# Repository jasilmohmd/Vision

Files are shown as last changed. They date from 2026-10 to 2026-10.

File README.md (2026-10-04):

ï»¿# Hands-free photography rig

Follow SOFTWARE_PLAN.md for the interface contract and phase requirements.
Read [context/README.md](context/README.md), [context/HANDOFF.md](context/HANDOFF.md)
and STATUS.md before resuming work. Update context before every commit, as
required by AGENTS.md. Future-phase files are labeled placeholders.

## Phase 0 setup (PowerShell)

```powershell
python -m venv .venv
.\.venv\Scripts\python.exe -m pip install pyyaml pytest
.\.venv\Scripts\python.exe -m app.main --help
.\.venv\Scripts\python.exe -m app.main --config config.yaml --check-config
.\.venv\Scripts\python.exe -m pytest
```

Only PyYAML and pytest are needed for Phase 0. The requirements files list
later laptop and Uno Q dependencies. Ultralytics is laptop-only for export;
never install it or PyTorch on the Uno Q.

Use --check-config to validate configuration without starting devices. Phase 3
adds --mock, --mic laptop|udp (default udp), --preview and --seconds.
Relative photos_dir values resolve beside the selected YAML file. IP defaults
are examples awaiting confirmation at Gate 0. Ports follow the source contract.

## Phase 1 vision (PowerShell)

The laptop runtime uses **opencv-contrib-python** for CSRT/KCF, replacing the
base OpenCV package from the original scaffold. Uno Q requirements use its
headless contrib equivalent. Install one cv2 distribution per environment:
[OpenCV package guidance](https://pypi.org/project/opencv-contrib-python/).

```powershell
.\.venv\Scripts\python.exe -m pip install "opencv-contrib-python>=4.10,<5" onnxruntime numpy
.\.venv\Scripts\python.exe -m tools.download_models
```

YOLOv8n exports at 320 pixels with a static FP32 batch-one input and raw outputs
(no embedded NMS). Export dependencies live in a separate laptop environment
because Ultralytics depends on base OpenCV:

```powershell
python -m venv .venv-export
.\.venv-export\Scripts\python.exe -m pip install -r requirements-export.txt
.\.venv-export\Scripts\python.exe -m tools.export_onnx
```

The downloader fetches official YuNet and Vosk small English models. The shell
wrapper is `bash tools/download_models.sh` (set PYTHON to your venv Python on
Linux). Models and benchmark reports live in ignored models/; downloads need
internet, but runtime inference runs locally using ONNX Runtime and OpenCV.

```powershell
.\.venv\Scripts\python.exe -m tools.demo_vision --target person
.\.venv\Scripts\python.exe -m tools.bench_vision --frames 100 --output models/benchmark-webcam.json
.\.venv\Scripts\python.exe -m pytest
```

Move across the webcam view and confirm the box follows smoothly. The preview
shows the target and normalised dx/dy; the console prints the box and offset
per frame. Press Q or Escape to exit. Positive dx is right, positive dy is down,
and (0, 0) means centred; absent targets return (None, None).

Use --target face|dog|cat, --tracker KCF, --source 1 for another webcam, or
--source path/to/video.mp4. A video file is useful for repeatable benchmarks.
Demo --headless --frames 100 prints offsets without opening a window.
Benchmarks exclude acquisition time, preload the same 320x240 frames for both
runs, and report detected/tracked frame counts; a run without a target does not
measure normal tracking performance. CSRT is preferred with KCF fallback;
detection refreshes every configured N frames and immediately after a failure.
New boxes associate with the closest previous box centre; confidence chooses
the initial target. A missing detection clears the active target.

Ultralytics YOLOv8 weights are AGPL-3.0, as noted in SOFTWARE_PLAN.md.
Model/export references: [Ultralytics ONNX export](https://docs.ultralytics.com/modes/export),
[OpenCV YuNet](https://github.com/opencv/opencv_zoo/tree/main/models/face_detection_yunet),
[Vosk models](https://alphacephei.com/vosk/models),
and [FaceDetectorYN API](https://docs.opencv.org/4.x/df/d20/classcv_1_1FaceDetectorYN.html).

## Phase 2 voice (PowerShell)

```powershell
.\.venv\Scripts\python.exe -m pip install vosk sounddevice
.\.venv\Scripts\python.exe -m tools.demo_voice --list-devices
.\.venv\Scripts\python.exe -m tools.demo_voice --list-commands
.\.venv\Scripts\python.exe -m tools.demo_voice --mic laptop --device 3
```

Device 3 was this laptop's AMD microphone array during development; the default
input was a virtual Elgato line. Check device IDs on each machine and choose the
actual microphone; this does not change the system default. Ctrl+C stops the demo.
Use --seconds 30 for a finite run. Events are printed as JSON: heard, command
(with a typed action/target/direction/small-step flag), or low_confidence.
The standalone Phase 2 demo prints events only. The Phase 3 app applies commands.

Vosk uses all 19 exact "camera <command>" phrases plus [unk]. A final command
requires the leading wake word and confidence at or above config.vosk_conf_threshold
for every word, including "camera". Empty/[unk] results are ignored; other rejected
non-empty results emit low_confidence. Partial "camera" emits heard once per utterance.

Keep quiet for the two-second startup microphone sample, then wait for Ready.
Speech is separated after about 0.7 seconds of quiet, retaining a short lead-in
so the wake word is not cut off. Say one complete command at a time and pause
for its response. Commands still require the full wake phrase and word
confidence threshold. Closing the app discards unfinished speech rather than
turning it into a command. Loud startup samples are bounded; actual headset,
quiet speech and background-chatter reliability still need live checks.

Run the guided acceptance check from 0.5-1 m away:

```powershell
.\.venv\Scripts\python.exe -m tools.demo_voice --device 3 --checklist --report logs/phase2-voice-check.json
```

Say each prompted phrase, pause for its command event and repeat if rejected.
After all 19 commands, talk normally for the prompted 20-second background test,
without saying command phrases. It should produce no command events. The summary
records coverage and false commands, not raw audio or chatter transcripts. A
passing summary still needs confirmation that the distance and chatter conditions
were actually exercised. No recording is saved. Ctrl+C produces an incomplete
summary if you stop early. --background-seconds can adjust the test duration.

UDP mode is also runnable without real hardware:

```powershell
.\.venv\Scripts\python.exe -m tools.demo_voice --mic udp --seconds 30
```

It binds config.audio_port (5005 by default) on 0.0.0.0. Each datagram must contain
512 mono s16le samples (1024 bytes) at 16 kHz. A bounded arrival-order queue buffers
jitter, drops old backlog and inserts 32 ms silence chunks for missing playout slots.
The raw contract has no sequence numbers/timestamps, so it cannot reconstruct packet
reordering or exact losses. Before any valid packet, read_chunk returns empty on
short timeouts. Closing the source releases its receiver thread/socket.

API references: [Vosk microphone example](https://github.com/alphacep/vosk-api/blob/master/python/example/test_microphone.py),
[Vosk recognizer API](https://github.com/alphacep/vosk-api/blob/master/python/vosk/__init__.py),
[sounddevice raw streams](https://python-sounddevice.readthedocs.io/en/latest/api/raw-streams.html).

For no-response diagnosis, demo_voice --levels prints input RMS/peak once per
second and the selected input name. Verify --list-devices after connecting a
headset; IDs can change. Nonzero changing levels show capture activity, not
successful recognition. Headset tests are diagnostic and do not by themselves
replace the planned laptop-microphone acceptance at 0.5-1 m.

## Phase 3 mock rig (three PowerShell terminals)

Install laptop dependencies with `.\.venv\Scripts\python.exe -m pip install -r requirements-laptop.txt`.
Models must already exist locally (see Phase 1/2 setup above). From the repository
root, run one command in each terminal. Start the camera mock first and wait
for "Mock camera ready" before starting the app (webcam startup can take a while):

```powershell
.\.venv\Scripts\python.exe -m tools.mock_camera
.\.venv\Scripts\python.exe -m tools.mock_voice_unit --device 4
.\.venv\Scripts\python.exe -m app.main --mock --preview
```

Device 4 is the verified boAt headset on this laptop; check `tools.demo_voice
--list-devices` before using another computer. The voice mock sends live 16 kHz
mono s16le audio in 1024-byte UDP packets, and prints light states/colours. The
app uses UDP audio by default; `--mic laptop --device N` bypasses the voice mock
for diagnosis. It does not change the system microphone setting.

Wait for "Ready", say **camera track person**, then move left/right. The camera
mock shifts its 320x240 crop inside the full webcam image; the preview shows the
box, offsets and pan/tilt. A narrow crop may require standing farther back or
moving into its initial centre. Say **camera shoot**, check the `saved` white
flash in the voice console, and open http://localhost:8080. Tap the newest photo
to open its full resolution. The gallery refreshes when a new photo is saved.
Press Q in the preview, then Ctrl+C in both mock terminals.

Manual direction/small-step/centre commands work while idle or tracking. Stop
tracking returns to idle; sleep ignores commands until camera wake. Burst saves
three photos about 400 ms apart after centering; timer flashes blue three times
then shoots. Missing subjects produce nosubject after two seconds. Movement is
limited to ten requests per second and configured angle limits. Captures wait
for centering or the configured timeout, save before ACK, and retain camera
photos if saving fails. A failed ACK is retried before another capture.

`photos/` (including index metadata), model files and diagnostic logs are Git
ignored. Runtime needs write access to photos_dir. Only one app instance may
write the same photo directory. Optional `speaker_enabled: true` uses eSpeak NG
or eSpeak when installed; disabled/missing synthesis is a no-op.

For headless diagnostics, camera `--synthetic` or `--image path.jpg` avoids the
webcam; voice `--silence` avoids microphone access; all three support --seconds.
The mock HTTP/UDP ports match the shared contract exactly. `--mock` only changes
camera/light destination addresses to localhost; real board/network integration
waits for the plan's hardware gates. Firmware is owned by separate Session B.

## Phase 5 Uno Q deployment

See [deploy/README.md](deploy/README.md) for source/model transfer, the Linux
installer, laptop LAN mocks, phone-gallery acceptance and Uno Q benchmark.
S3/C3 IPs are deferred; this phase uses laptop mocks. Do not run --mock on Uno Q
when its mock servers are on the laptop; use the separate config.phase5.yaml.

## Live tracking view on Uno Q

After confirming hardware gates and updating board addresses in config.yaml,
run from the deployed project directory:

```bash
.venv/bin/python -m app.main --config config.yaml --mic udp --seconds 0
```

Open `http://<UNOQ_IP>:8080/live` on the laptop or phone on the same network.
The page shows the existing camera feed with its tracking box, mode, pan/tilt
and offsets; it does not open another S3 stream. Say **camera track person**
to follow a person and **camera stop tracking**, then pause, to return to IDLE.
Use the Camera roll link for saved photos. Ctrl+C in the app terminal stops
the run; `--seconds 0` has no time limit.

Current hardware blockers and the temporary serial-reader workaround are
recorded in [power diagnosis](context/HARDWARE_POWER_ISSUE.md) and
[C3 audio diagnosis](context/FIRMWARE_AUDIO_ISSUE.md). Publication does not
mean these hardware acceptance checks have passed.

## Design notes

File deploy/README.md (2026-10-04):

# Phase 5: Uno Q against laptop mocks

## Prepared robustness service (2026-10-04)

The requested robustness implementation includes `photo-rig.service`.
It runs the UDP microphone app from `/home/arduino/Vision` as `arduino`, waits
for network startup and restarts after exit. It is prepared, not installed or
enabled: hardware acceptance and the S3 power correction remain pending.
Use the real-board `config.yaml`, verified current addresses, models and venv.
Do not use `config.phase5.yaml` for the service.

When hardware acceptance permits activation, on the Uno Q:

```bash
cd /home/arduino/Vision
.venv/bin/python -m app.main --config config.yaml --check-config
systemd-analyze verify deploy/photo-rig.service
sudo install -m 644 deploy/photo-rig.service /etc/systemd/system/photo-rig.service
sudo systemctl daemon-reload
sudo systemctl enable --now photo-rig.service
systemctl status photo-rig.service
journalctl -u photo-rig.service -n 50 --no-pager
```

Stop any manually launched app first so its UDP/gallery ports are released.
If using another directory or user, update the unit paths before installation.
To stop auto-start: `sudo systemctl disable --now photo-rig.service`.
The app writes JSON lines to `logs/vision.jsonl`, rotates at UTC midnight and
keeps seven rotated files. `--log-dir` overrides the destination. Camera outages
mask the normal light state with `reconnect`; recovery synchronizes servo
positions and recreates the tracker for the retained target. Missing valid C3
packets for over five seconds warns once per outage without stopping the app.
Generated silence does not count as incoming C3 audio. Sleep keeps the light off.
See `tools/prototype_acceptance.md` for the later combined hardware check.

This phase deploys the Linux software and models and measures Uno Q performance.
No S3/C3 addresses, firmware flashing or systemd service are required. Physical
integration begins only at later gates. Service/autostart work belongs to Phase8.

## Known network and login

User supplied Uno Q LAN IP10.153.76.45 and confirmed SSH/hotspot readiness.
Laptop Wi-Fi IP10.153.76.189 was observed locally when preparing this phase.
Recheck both after changing networks. User confirmed SSH username arduino; no password is stored in scripts or context. The laptop and Uno Q must be mutually reachable,
not merely have access to the same hotspot; disable hotspot client isolation if
it prevents this. Keep host-key verification enabled.

## Copy and install from PowerShell

From the repository root:

```powershell
.\deploy\copy_to_unoq.ps1 -User arduino -UnoqIp 10.153.76.45 -LaptopIp 10.153.76.189
```

This packages runtime source and the three required models, copies two archives
via scp to ~/Vision, then runs the installer over SSH. SSH/sudo prompts are entered
in your own terminal, never in chat. Existing photos and normal config.yaml are
preserved. Generated config.phase5.yaml intentionally points both mock endpoints
at the laptop IP; do not use it as a real-board config. Archives/source/model
checksums and generated local config are in ignored logs/. Firmware, photos,
export .pt weights, virtual environments and secrets are excluded from transfer.

`-SkipInstall` only copies/extracts. On the Uno Q, install/check separately:

```bash
cd ~/Vision
bash deploy/install_unoq.sh
# Already prepared OS packages: add --skip-apt
# Recheck existing runtime without installs:
bash deploy/install_unoq.sh --check-only
```

Installer creates project .venv, installs headless contrib/ORT/Vosk/Flask etc.,
verifies models and writable storage, and writes logs/phase5-preflight.json.
It installs missing Debian python3/venv/pip/libgomp/libatomic packages if needed.
No export dependencies on Uno Q. Missing binary wheels stop installation rather
than build OpenCV/ORT from source. Record architecture/Python and the exact error
if this happens. Setup downloads packages; runtime model inference works offline.
Use a different -RemoteDirectory if ~/Vision is used by another deployment.

## Run laptop mocks

On the laptop, in separate terminals, select your actual microphone device ID:

```powershell
.\.venv\Scripts\python.exe -m tools.mock_camera --bind 10.153.76.189
.\.venv\Scripts\python.exe -m tools.mock_voice_unit --host 10.153.76.45 --bind 10.153.76.189 --device MIC_ID
```

Device IDs can change after reconnecting; choose the current input with demo_voice --list-devices.
Wait for camera ready before running the Uno Q app. Allow this project Python
through Windows Firewall for the shared network if prompted. Required traffic:
Uno Q -> laptop TCP80/81 and UDP5006; laptop -> Uno Q UDP5005; phone -> Uno Q TCP8080.
The default camera mock binds localhost, so --bind is essential for LAN testing.
Stop the laptop app; the app now runs only on Uno Q and laptop only runs mocks.

## Run app on Uno Q and accept from phone

```bash
cd ~/Vision
.venv/bin/python -m app.main --config config.phase5.yaml --mic udp
```

Do NOT add --mock here: localhost would mean the Uno Q, not the laptop. Do NOT
add --preview to the headless runtime. Say camera track person and move inside
the laptop webcam view; view http://10.153.76.189:81/stream from a laptop browser
to observe the crop. Say camera shoot and confirm saved in the mock light console.
From a phone on the same network, open http://10.153.76.45:8080 and confirm the
newest photo opens at full resolution. Stop the app with Ctrl+C before benchmarking.
No physical NeoPixel is needed for the mock's printed light message.

## Benchmark on Uno Q

With laptop camera mock still running and a person visible in its crop:

```bash
cd ~/Vision
.venv/bin/python -m tools.bench_vision --config config.phase5.yaml --source http://10.153.76.189:81/stream --target person --frames 100 --output logs/phase5-benchmark.json
```

Record detected/tracked frames and detector-only/detector+tracker FPS, architecture
and Python/library versions from preflight. This benchmark excludes acquisition
and preloads frames; it is CPU processing FPS, not end-to-end network throughput.
Do not treat a no-subject run as a representative tracking benchmark.
If tracking is slow, benchmark --tracker KCF and start app --tracker KCF, or raise
detect_every_n_frames in config.phase5.yaml and measure again. Changing static
ONNX input size requires a fresh laptop export; never install export tools on Uno Q.

Return preflight, benchmark numbers, phone-gallery and voice/tracking/photo results.
Update STATUS/context with actual results before committing. Phase5 remains
incomplete until these checks pass. Stop at SOFTWARE_PLAN GateA afterward.

References: [Arduino Debian/SSH guide](https://docs.arduino.cc/tutorials/uno-q/debian-guide/),
[ONNX Runtime Python platforms](https://onnxruntime.ai/docs/get-started/with-python.html).

## Current prepared USB test deployment (2026-10-04)
The current DHCP observations are Uno Q10.153.76.45 and laptop10.153.76.189.
Recheck these before testing; the earlier addresses above are historical examples.
User installed ADB separately and confirmed USB device serial662499217. The
latest source was copied over USB into /home/arduino/Vision-phase5-20261004,
with its own models/config/photos and the existing ~/Vision runtime venv.
Original ~/Vision is retained. Runtime/model preflight passed; live acceptance
and benchmark are deferred until the user is ready. App Lab is not required
for this direct Linux Python workflow.

When ready, start the camera/voice mocks on the laptop using the current IPs
and confirmed headset device. From the user's Platform Tools directory:

```powershell
.\adb.exe -s 662499217 shell -t "cd /home/arduino/Vision-phase5-20261004 && .venv/bin/python -m app.main --config config.phase5.yaml --mic udp"
```

Keep this terminal open. Once a photo is saved, the phone gallery is
http://10.153.76.45:8080 on the same network. After stopping the app, keep the
laptop camera mock running and benchmark:

```powershell
.\adb.exe -s 662499217 shell -t "cd /home/arduino/Vision-phase5-20261004 && .venv/bin/python -m tools.bench_vision --config config.phase5.yaml --source http://10.153.76.189:81/stream --target person --frames 100 --output logs/phase5-benchmark.json"
```

Do not report Phase5 passed from preflight alone. SSH also listens on port22,
but the new IP's host key has not yet been enrolled in the laptop's SSH client;
use the trusted USB connection to verify it rather than disabling verification.

## Stream troubleshooting and quote-safe runner

After copying the latest source, use the Linux runner to avoid Windows SSH command
quoting problems. It checks for existing app processes and stops on guard errors:

```bash
bash deploy/run_phase5.sh network   # 60s read-only camera status/stream check
bash deploy/run_phase5.sh live      # ten-minute app; stop old app first
bash deploy/run_phase5.sh benchmark # 100 person frames; stop app first
```

Network results go to logs/phase5-network-unoq.json. The check counts received
JPEGs and chunk gaps; it does not capture/save photos, ACK, move, or benchmark
inference. A steady local stream with remote timeouts needs network diagnosis;
keep firewall enabled and examine the shared hotspot connection. Do not count
runtime setup or HTTP gallery access as full spoken/phone acceptance.

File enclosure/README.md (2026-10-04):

# Vision enclosure models

Self-contained, editable OpenSCAD code for all seven designs in the supplied
`ENCLOSURE_PROMPTS.md`. The reference is at `../../ENCLOSURE_PROMPTS.md` relative
to this folder. No libraries are required. All dimensions are millimetres.

## Use

1. Open `vision_enclosures.scad` in OpenSCAD, or paste its entire contents into
   the playground, replacing the example code.
2. Change `part = "layout";` to a selection from the table below.
3. Replace the typical component sizes and the explicitly marked position
   placeholders near the top of the file with measurements.
4. Preview, render, then export one selected part as STL. In desktop OpenSCAD,
   use F5 for preview and F6 for render, then File > Export > Export as STL.
5. Use `camera_assembly` and `preview_tilt` to inspect the camera arrangement.
   This view omits purchased servos, horns, screws, boards and cables. It is
   not an STL to print and does not constitute a collision or load test.

| Selection | Result |
| --- | --- |
| `layout` | Eight separate pieces laid out for viewing, using horizontal C1 |
| `camera_assembly` | Assembled camera enclosure preview |
| `C1` | Pan pod with horizontal-axis tube clamp and tripod nut pocket |
| `C1_vertical` | Alternative with vertical-axis tube clamp behind the pod |
| `C2` | Pan yoke, tilt-servo window and pivot spacer |
| `C3` | Camera front shell, PCB ledges and hinge mounting plates |
| `C4` | Camera rear bay, perfboard rails, vents and strain-relief bridge |
| `P5` | Voice enclosure with breadboard locator, spare bay and strap ears |
| `P6` | Matching voice lid |
| `P7_front` | Mic pod half containing the angled NeoPixel diffuser |
| `P7_back` | Other mic pod half |

Example:

```scad
part = "C3";
```

The nine default STL exports and two previews are in `validation/`. They are
prototype exports using typical sizes, not measurement-approved production files.
Regenerate them after changing parameters. Never export the layout as one part.

## Deliberate corrections and prototype limitations

The reference contains conflicting dimensions and printing constraints. These
models resolve some geometrically and make the remaining limits explicit:

- Camera outer body: **40.8 x 76.8 x 39.6 mm**. Its larger footprint allows for
  the 30 mm perfboard and corner fasteners, beyond the 28 mm camera PCB.
- Rear depth: **25.6 mm**, derived from 10 mm header separation + 1.6 mm perfboard
  + 12 mm component space + 2 mm rear wall. The original 20 mm cannot hold that
  stack. Actual pin lengths and capacitor clearance still need checking.
- Hinge plates extend rearward from C3 to put the tilt axis at assembled
  mid-depth. The original 10 mm circular boss cannot contain a 20 mm horn.
  The enlarged horn pocket takes a conservative 20 mm hub-to-tip length.
- Yoke inner gap: **69.8 mm**, allowing 11.5 mm per side beyond the case bosses.
  This includes the provisional 8.5 mm servo projection and 2 mm horn thickness.
  A matching spacer on the pivot arm fills its extra distance. The base is
  **76.4 x 44.8 mm**, expanded to contain both the arms and the horn pocket.
  Measure the servo tab-to-output-face distance before selecting final spacing.
- The tilt axis remains 48 mm above the plate top. Its height also increases
  automatically if the case diagonal grows. This gives a conservative body-to-
  plate envelope, but does not check ribs, cables, screws or the actual servo.
- C1's bearing ring is approximately **37.77 mm inside diameter, 9 mm tall**:
  its diameter clears the off-centre servo body and its height follows the
  assumed servo/horn stack. A 30 mm ring only 1 mm above the mounting tabs would
  collide with that body or fail to reach the yoke. The bearing surface is not
  a load-rated bearing. The pod is intentionally thick around the mount.
- The vertical clamp is offset behind the pod to keep its tube bore open.
  C1's origin is the pan shaft axis at bed height, rather than the centre of
  its asymmetric tripod flange footprint. The horizontal clamp has a 90-degree
  mouth (270-degree wrap). Interference is diametral and requires a fit coupon.
- The camera USB cut-outs continue into the rear rim where needed. The cable
  notch opens to that rim for assembly and avoids tiny detached tabs.
- C3's optional outward lens hood defaults to **off** (`camera_hood = 0`) so
  its front lies flat on the bed. Set it to 1.5 for a hood and revise supports
  or print orientation. Labels are 0.6 mm engravings, rather than raised text
  underneath the print. They are optional.
- Voice interior: **96.8 x 49.6 x 30 mm**. Space is reserved for the breadboard
  and optional battery/charger, but the spare bay has no battery-specific clips
  or charger standoffs. Secure and insulate those components separately. USB
  positions are placeholders. Strap slots are external ears to isolate straps
  from the electronics.
- P7 uses a **30 mm nominal diameter x 52 mm nominal length** capsule to make
  room for the mic, header space, LED and 12 mm arm socket. Its ports remove
  the extreme tips; the angled diffuser also projects above the capsule.
  Both halves print with their split planes on the bed. Front screw seats use
  counterbores, not conical countersinks. The diffuser is a 1 mm solid window
  angled 30 degrees; use translucent/natural material. Transmission is untested.
- `mic_sound_x` and `mic_sound_z` must match the actual acoustic port, and the
  module's acoustic side must face the tip. The two clamped halves capture it;
  the 0.8 mm retaining rim is a local exception to the 1.2 mm minimum feature.
- Curved clamp bores, horizontal pivot/horn pockets, rear guides, the offset
  vertical clamp platform and pod roofs may need supports or reorientation.
  **Support-free printing, uniform 3 mm fillets, all overhangs below 45 degrees,
  and bridges below 20 mm have not been achieved or certified.** Rounded planar
  footprints use chamfers; curved clamps/pods do not have universal bottom chamfers.
- Camera rear fasteners pass through the deep bay, so the reference's M2 x 6 mm
  screws are too short. Allow roughly 30-32 mm screw length (verify head seating
  and engagement). The enlarged pivot spacer also needs a longer pivot screw.
  Select actual screw and clamp-bolt lengths after the fit test.

## Validation performed on 2026-10-04

Rendered with the official portable OpenSCAD 2021.01 Windows build from the
[OpenSCAD download page](https://openscad.org/downloads.html), without installing
it system-wide. Each of the nine part exports reported `Simple: yes`.

`python enclosure/check_meshes.py` checks the exported ASCII STLs using the
Python standard library. All nine default exports passed: one connected mesh,
every edge shared by two faces, consistent edge winding, no zero-area triangles
and positive signed volume. See `validation/mesh_report.json` and individual
render logs. Layout and camera assembly previews were visually inspected.

These checks establish default-export geometry only. They do not establish
component fit, arbitrary parameter combinations, slicer support requirements,
clamp holding force, servo torque, thermal performance, acoustics, or full
pan/tilt motion. No hardware or software-phase acceptance is inferred.

Before printing the full set, measure the components, make a clamp/horn/lip fit
coupon, inspect each sliced layer, and assemble and sweep the mechanism on a
bench. Confirm sound-port alignment and secure mounting before use near a person.

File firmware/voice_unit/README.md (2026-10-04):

# C3 voice unit (F3)

User-confirmed C3 SuperMini wiring: INMP441 SCK GPIO4, WS GPIO5, SD GPIO6,
VDD3V3, common GND, L/R grounded. External NeoPixel DIN GPIO7, GRB, brightness40.
F1 microphone conversion uses SHIFT14. Optional IR is omitted in this prototype.

Copy ../secrets.example.h to ignored secrets.h and enter Wi-Fi credentials
locally. UNOQ_IP is the audio receiver's confirmed address, not the C3 address.
Use the laptop destination for the standalone bench checker; use the Uno Q
destination for integration. Initial addressing may use WIFI_USE_DHCP=1 to read
the C3 address from Serial. Static production addressing requires confirmed
C3_IP/GATEWAY/SUBNET; never invent those values. No credentials belong in Git.

The audio task reads mono left-channel I2S at16kHz/32bits, clips after SHIFT,
and sends exactly512 signed16bit little-endian samples per UDP5005 datagram.
It drains audio while offline and does not replay a disconnected backlog.
The main loop independently receives UDP5006 light states, using timers rather
than blocking flash/blink delays. heard/saved last300ms; error gives two150ms
red flashes with150ms gaps, then the previous steady state. Wi-Fi down overrides
the display with blinking purple. Unknown/malformed light messages are ignored.
Automatic reconnect remains enabled; manual retries wait45s for an in-progress WPA3 handshake. Serial prints disconnect reason, IP, reset reason, packet send counts,
send errors and signal level. Successful UDP send is not receiver acknowledgement.

From repository root, with the portable toolchain and installed libraries:

```powershell
& ./firmware/.toolchain/arduino-cli.exe compile --fqbn 'esp32:esp32:esp32c3:CDCOnBoot=cdc' --libraries ./firmware/.toolchain/user/libraries --build-path ./firmware/.build/voice_unit ./firmware/voice_unit
# Upload only after explicit user authorization and verifying the C3 port.
& ./firmware/.toolchain/arduino-cli.exe upload --fqbn 'esp32:esp32:esp32c3:CDCOnBoot=cdc' --port COM18 --input-dir ./firmware/.build/voice_unit ./firmware/voice_unit
```

Read Serial115200 for the DHCP address. PortCOM18 is the observed C3 connection,
not a guaranteed permanent port. If USB upload fails, use the already-tested
BOOT/reconnect procedure and retry only after the user confirms readiness.

Run firmware/tools/check_voice_unit.py on the configured audio receiver:

```powershell
./.venv/Scripts/python.exe firmware/tools/check_voice_unit.py --ip <C3_IP>
```

Stop other UDP5005 receivers first. This intentionally records five seconds of
microphone audio locally into ignored firmware/.build/voice_checks/check.wav
and cycles all light states. Get the user's readiness before recording/colour
checks. Raw packets have no sequence header, so packet loss is only estimated
from expected rate, never exactly measured. Listen to the WAV and observe the
physical colours before claiming acceptance. Compilation/boot alone does not
establish microphone quality, colour accuracy or end-to-end voice recognition.

Earlier build2026-10-04: compiled and flashed999581 program bytes/37976 globals,
verified C3 COM18/ESP32-C3 AZrev1.1. Explicit SAE-both negotiation is enabled.
Wi-Fi authentication still expires on the tested WPA3 hotspot; no C3 DHCP IP
confirmed yet. Packet, microphone quality and physical light checks are pending.
Try the existing hotspot in2.4GHz/WPA2-Personal with its unchanged current
password before additional firmware changes; this is a diagnostic next step,
not a claim that the ESP32-C3 lacks WPA3 support. Confirm actual network details
before changing destinations or declaring acceptance.

For C3 headers, select C/C++: Select a Configuration -> ESP32-C3 SuperMini in
VS Code/Cursor, then reload the editor window. The workspace provides separate
S3 and C3 compiler/SDK paths and associates .h/.ino with C++; pragma once itself
is valid and the full C3 sketch compiled successfully. Keep headers' board
configuration matched to the current sketch. Editor paths are validated locally;
visual diagnostic clearance still requires checking the editor.

## Latest Wi-Fi troubleshooting

The default-power Wi-Fi-only sketch detected the WPA2 hotspot at-47dBm but
failed to connect. The diagnostic capped transmit power at8.5dBm (ESP-IDF34)
and confirmed DHCP10.153.76.243, gateway10.153.76.224, RSSI around-43dBm.
Production now applies the same cap after starting STA, before connecting.
It compiled999841 program bytes/37976 globals and uploaded with verified hashes.
After restoration,10.153.76.243 answered two pings and its neighbour entry matched
C3 MAC44:b1:76:17:f5:7c. Serial showed packet-send counts240/553/866; five initial
send errors did not increase in those subsequent reports. This establishes
connection and sender activity, not receipt or microphone quality.
This is an observed working setting for this board/network, not proof of an
antenna/power fault or a universal fix. Production connectivity and F3 audio/
light acceptance must be checked separately. Diagnostic source is preserved
under ../bench/wifi_diagnostic; credentials remain ignored.

## Nonblocking diagnostic logging — prepared 2026-10-04
Audio/event tasks enqueue bounded debug messages without waiting. Main loop
drains only when USB has capacity; CDC TX timeout is zero. Full queues drop logs
instead of delaying PCM delivery. Compile passed on core3.3.11:999975 program
bytes/37976 globals. This repair is NOT flashed yet; hardware testing is deferred.
After confirmed flashing, run sustained delivery with serial monitor CLOSED for
at least40seconds, measure rate/max gaps, then verify speech and light patterns.
See ../../tools/prototype_acceptance.md. IR remains omitted.

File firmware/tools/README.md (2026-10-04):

# Hardware checks

verify_toolchain.ps1 compiles the F0 probe; verify_bench.ps1 compiles all four
F1 bench sketches with optional simultaneous-servo variant. Neither uploads.
See ../TEAM_TESTING.md for manual upload commands and physical acceptance.

Phase F2: check_camera.py --ip <S3_IP> exercises status, a small servo pattern,
QVGA MJPEG, higher-resolution capture, retained-photo retry, ack and stream
recovery. Requires requests. JPEGs default to ignored ../.build/camera_checks/.
The checker also moves pan/tilt through85..95degrees during active streaming,
prints each move latency, requires acknowledgements below2s, and checks
commanded slew plus fresh video frames. These are software readbacks; the user
must still verify actual direction, smoothness and return to neutral.
Target/command readback cannot measure physical servo position; observe motion.
Do not run simultaneously with the app: the stream server serves one viewer.

check_voice_unit.py remains a Phase F3 task.

Phase F3: check_voice_unit.py --ip <C3_IP> runs on the configured audio receiver.
It records5s of UDP5005 PCM to ignored .build/voice_checks/check.wav, checks1024
byte packet sizes and observed rate/RMS/peak, then sends all8 light states.
User readiness is required before the microphone/colour checks. It cannot
measure exact packet loss because the contract PCM datagrams have no sequence
numbers; estimated rate shortfall is reported explicitly. IR remains omitted.

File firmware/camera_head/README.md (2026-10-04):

# S3 camera head (F2)

Board: user-confirmed ESP32-S3 CAM N16R8, OV3660. GPIO1 pan, GPIO2 tilt.
Camera signals match the supplied pinout and installed core ESP32S3_EYE entry;
PWDN/RESET are -1 in that entry and must be validated by camera initialization.
OPI PSRAM is required. F1 horns were aligned at 90/90; this sketch centres on
boot without an automatic sweep. There is no physical position feedback.

Copy ../secrets.example.h to secrets.h and configure Wi-Fi locally. Never commit
secrets.h. Production defaults to static addressing; user approved
WIFI_USE_DHCP=1 for the first bench check. All devices need the same 2.4 GHz
network without client isolation.

From repository root (portable toolchain used in this workspace):

```powershell
& ./firmware/.toolchain/arduino-cli.exe compile --fqbn 'esp32:esp32:esp32s3:PSRAM=opi,FlashSize=16M' --libraries ./firmware/.toolchain/user/libraries --build-path ./firmware/.build/camera_head ./firmware/camera_head
# Run upload only after Gate F2 confirmation; recheck the connected board/port.
& ./firmware/.toolchain/arduino-cli.exe upload --fqbn 'esp32:esp32:esp32s3:PSRAM=opi,FlashSize=16M' --port COM19 --input-dir ./firmware/.build/camera_head ./firmware/camera_head
& ./.venv/Scripts/python.exe firmware/tools/check_camera.py --ip <IP_FROM_SERIAL>
```

Serial115200 reports PSRAM, camera PID, IP, capture dimensions and errors.
HTTP control is port80; MJPEG is port81. Stream is QVGA320x240 JPEG quality12.
Video is capped at10fps to leave Wi-Fi airtime for control requests. Servo
targets and PWM updates have a separate mutex from camera frame acquisition;
a slow frame cannot hold the servo lock. Capture still freezes servo updates
while acquiring the photo. The checker also measures move latency and checks
commanded slew while an active stream is being consumed. Physical direction
and actual movement require observation; status angles are software commands.
Servo slew runs in a dedicated task, independently of Wi-Fi reconnect work in
the Arduino loop, with at most2degrees per20ms and no burst to catch up missed
periods. Status diagnostics move_received_ms, move_settled_ms and
move_in_progress measure command handling and completion of commanded PWM
updates, not physical servo position. Millisecond values wrap after49days.
Serial logs each accepted move with handler duration; speech recognition
latency on the laptop is outside this firmware's timing measurements.
Capture attempts QXGA2048x1536, then lower sizes if capture/allocation fails;
QXGA2048x1536 has decoded successfully in real bench and voice capture tests.
JPEG is retained until /ack; repeated /capture returns the same held image.
Capture freezes servo updates and excludes stream frame acquisition; stream
resumes at QVGA. Ordinary streaming uses a separate lock from servo control.
Video transmission also pauses while the JPEG is sent, leaving the servo mutex
released. Slow links can cause an app reader with a short timeout to reconnect.
Still responses use chunked HTTP transfer; JPEG content/type contract is unchanged.
Move targets clamp to pan10..170, tilt40..140, with2degrees/20ms slew.
The check uses only85..95degrees; it does not exercise mechanical end stops.

Only one stream viewer at a time. Close phone/browser/app stream before the
checker, and close the checker before starting the existing software app.
Live integration, Wi-Fi reconnect, prolonged operation and image quality are
hardware acceptance items; compilation alone does not establish them.

Observed DHCP bench IP: 192.168.29.231 (recheck Serial after reconnect).
After switching to the user's closer hotspot, Serial reported10.153.76.67
and RSSI-37dBm; laptop10.153.76.189. These are DHCP observations, not permanent
addresses. The checker passed streaming move ACKs in0.14..0.43s on that link.
OV3660 PID0x3660 and8MB PSRAM confirmed; QXGA2048x1536 capture decoded
successfully. Wi-Fi varied from roughly-50 to-79dBm; weak-link timeouts and
intermittent live video remain an acceptance issue. No static IP chosen yet.
User confirmed both servos physically move smoothly and centre in the direct
camera-firmware test (pan70..110, tilt75..105). HTTP readback remains commanded
angles, not a physical position sensor.

## Commit handoff - 2026-10-04
The final dedicated-servo-task build was previously flashed successfully.
Subsequent normal-software tests using the boAt headset produced up/down/left/
right movements and centre acknowledgements; the user confirmed all four
correct and smoothly centred. This is user-observed physical evidence, not
servo position feedback. Full F2 acceptance remains pending: intermittent
MJPEG timeouts, final-build capture/ack/stream recovery and longer stability
checks still need confirmation. C3 production voice firmware/F3 is deferred.
The software phrase-ending fix is a separate commit (64994af).

## Editor include paths
Open the repository root in VS Code/Cursor with the Microsoft C/C++ extension.
.vscode/c_cpp_properties.json selects the ESP32-S3 compiler, Arduino core3.3.11,
ESP32Servo and matching SDK headers. This resolves editor-only include lookup
for IPAddress.h in the ignored secrets.h; the Arduino CLI already builds it.
The configuration uses LOCALAPPDATA rather than a fixed username. It matches
this workspace's installed esp-x32 tool version2601 and ESP32 core3.3.11;
update the versioned paths if your machine uses different toolchain versions.
The compile database is generated by the documented camera compile command;
header files also have explicit fallback include paths. Arduino .ino files are
associated with C++. After configuration changes, reload the editor window
or run C/C++: Reset IntelliSense Database if stale red underlines persist.
Keep the configured secrets.h local and ignored.

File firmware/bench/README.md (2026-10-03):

# Bench sketches

Four implemented F1 sketches: servo_sweep (S3), neopixel_test, mic_level,
ir_test (C3). See ../TEAM_TESTING.md for wiring, compile/upload commands,
expected observations and reporting. Each runs independently; flashing a new
C3 sketch replaces the previous one. These bench sketches use no Wi-Fi/secrets.

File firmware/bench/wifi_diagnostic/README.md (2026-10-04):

# C3 Wi-Fi diagnostic

Temporary F3 troubleshooting sketch. Uses DHCP and the same ignored local
credentials as voice_unit. It scans for that network, reports channel/RSSI/auth,
then makes one connection attempt using the Arduino core connection defaults. No microphone,
NeoPixel, audio UDP, or servo tasks run. Credentials are never printed.

Copy voice_unit/secrets.h locally into this folder (secrets.h is ignored).
Compile for esp32:esp32:esp32c3:CDCOnBoot=cdc and upload only to the confirmed C3
with user authorization. Observe Serial at115200. A failed attempt stops after
30seconds; RESET starts another. After diagnosis restore production voice_unit
with user authorization. A successful connection does not pass F3 acceptance.

After the initial default-power baseline failed despite detecting the hotspot,
the diagnostic caps transmit power at8.5dBm (ESP-IDF value34, quarter-dBm units)
and reports set/read results for comparison. This is an experiment, not a claim
that the board has a power or antenna fault.

Events are queued from the Wi-Fi callback and printed in loop; DHCP addresses
are also printed every5seconds while connected. The final diagnostic confirmed
10.153.76.243 on the current WPA2 hotspot. This DHCP address may change later.

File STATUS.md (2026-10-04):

# Project status

## Session publication and resume point - 2026-10-04

User requested context refresh, commit and push of all pending project work.
Existing HEAD: d64f754f219d4b983a32bd87f740309fc2920e41.
Intended message: feat: add switchable BLE voice transport and network diagnostics.
Publication includes the previously implemented runtime freshness fix, network
migration/diagnostic changes, optional BLE transport and switching tools, tests,
and durable context. No additional firmware edits or hardware run in this
publication turn. Ignored credentials, models, logs and private media excluded.

Resume by reading context/README.md, HANDOFF.md, STATUS.md, BLE_TRANSPORT.md and
FIRMWARE_NETWORK_ISSUE.md. Full app is STOPPED. Current C3 mode BLE; verified
address44:B1:76:17:F5:7E. Uno Q USB ADB serial662499217, runtime/home/arduino/Vision.
Uno Q routerIP192.168.1.99; S3 last verified192.168.1.122; C3 Wi-FiIPunknown.
Root config.yaml retains prior hotspot addresses172.20.10.2/4/5; this is a stale
configuration snapshot, not current router addressing. Do not run it unchanged.

142 tests passed in9.73s after the final buffer change; diff whitespace check
passed. Strict final BLE40.019s:16004.26samples/s, no missing samples or padding,
but maxgap101ms fails <100ms requirement. NeoPixel colors not watched/unverified.
S3 status/stream timeout;0frames. No complete voice/camera integration acceptance.
Keep UDP selectable; switching is by reflash, not a live toggle. Shared canonical
UDP contract unchanged. Session A must not edit firmware under current rules;
Session B owns S3 connectivity and BLE sender follow-up. Do not advance phases.
Next action: diagnose S3 connectivity and remaining BLE timing in Session B,
then repeat strict BLE probe/physical light verification before full integration.
See the following entry and BLE_TRANSPORT.md for exact commands and measurements.

---

## Switchable BLE trial implemented; acceptance pending - 2026-10-04

User requested BLE while retaining Wi-Fi/UDP selection. Earlier in this work,
a narrow C3 BLE prototype was implemented/flashed under that request; current
Session A ownership instructions prohibit further firmware edits. Session B owns
firmware follow-up. SOFTWARE_PLAN section 2 is unchanged; BLE is experimental,
not an adopted replacement contract. See context/BLE_TRANSPORT.md for framing,
files, mode-switch commands and the measured results.

C3 currently runs BLE, address 44:B1:76:17:F5:7E. Uno Q receives INMP441 audio
and sends NeoPixel states over one connection; no headset/laptop microphone.
Both modes compile and BLE -> UDP -> BLE reflashing was verified, same partition.
UDP is still the default build/app mode; switching requires reflash in this trial.
C3 Wi-Fi authentication remains unresolved; its router DHCP address is unknown.
Uno Q 192.168.1.99, last verified S3 192.168.1.122. Existing full-system config
still contains old hotspot addresses: do not launch it unchanged on TinkerSpace.

Latest full local suite: 142 passed in 9.73s; focused BLE suite 6 passed in 0.30s.
Final serial-closed BLE probe: 40.019s, 640480 samples, 16004.26 samples/s,
zero missing/invalid/out-of-order samples, buffer drops or playout padding.
Maximum notification gap 0.101s narrowly exceeds the unchanged strict <0.100s
gate: report ok=false, transport acceptance PENDING. Prior probe had 272 padded
samples; startup cushion increased from 3 to 4 chunks (128ms) and eliminated
padding in this final sample. Earlier 40s loss-free result passed the older gate
before playout padding was measured; do not treat it as final acceptance.
Concurrent S3 read-only probe: 0 frames; status/stream timeout, ok=false.
Light writes requested previously; user says they did not watch NeoPixel, so
physical colors remain UNVERIFIED. No Vosk/full-command or standalone acceptance
in this trial. No private media saved. Full Vision app STOPPED; probes ended.

Next: Session B investigate S3 connectivity and remaining BLE timing; then
repeat strict BLE audio check, visually verify light colors, and run real voice/
camera integration using verified current config. Do not mark phases/gates done.
Existing HEAD d64f754f219d4b983a32bd87f740309fc2920e41. User subsequently authorized publication; see the newest publication entry
for the intended message and existing HEAD. Refresh context before any commit.

---

## Bluetooth alternative discussed - 2026-10-04

User interrupted further driver-report/toolchain inspection to ask about using
Bluetooth. No spare C3 available, user-reported. Previous temporary diagnostics
restored to production with verified uploads; Uno Q on TinkerSpace and app stopped.
No SDK install/downgrade or BLE implementation performed. Bluetooth is currently
an architectural option only: C3 INMP441 PCM needs32kB/s raw (16kHz16bitmono),
so BLE audio/light transport needs a measured throughput/reliability prototype;
camera remains Wi-Fi. C3 Wi-Fi/BLE share antenna, so BLE success cannot be assumed
if RF/hardware is implicated. Any production BLE transport changes require user
approval of shared SOFTWARE_PLAN section2 plus coordinated Session A/B work.
Next: respond to Bluetooth tradeoff, then obtain explicit direction before new
transport implementation or resume Wi-Fi driver/PHY diagnosis. No phase/gate
completion, commit/push, or automatic app restart. Existing HEADd64f754.

---

## Router isolation performed; no successful fix yet - 2026-10-04

User requested find/fix. Read FIRMWARE_NETWORK_ISSUE.md for exact tests/results.
C3 fails in Wi-Fi-only sketches without microphone/NeoPixel software activity;
sees router-62/-64dBm but cannot authenticate, even targeted BSSID/channel and
lower transmit power. Its temporary access point reports started but is absent
from fresh Uno Q scans. This narrows investigation to radio/driver/calibration,
RF/power or AP behavior; no board defect or root cause conclusively established.
S3 b/g and Uno Q powersaveOFF comparisons failed; both experiments reverted.
User says hotspots off and alternate power/cable ready; post-report probes still
fail. Do not claim independently verified physical supply changes.
Temporary C3 diagnostics restored to production1000105/37976; S3 production
986425/56664 restored. Uploads0/hashesverified. Uno Q router profile restored,
actualpowersaveON/default0, temporary NM profile/helper removed. All bounded
readers/probes ended. Vision STOPPED; old runtime config must not launch on
router until unknown C3 DHCP address is verified and all configs updated.
User spare-C3 availability question pending. Next: identified spare-board radio
comparison if available, otherwise Session B driver/PHY and hardware/RF/AP logs.
No erase/NVS reset, guessed pins, future-phase work, commit or push. Existing
HEADd64f754f219d4b983a32bd87f740309fc2920e41. Prior136 software tests unchanged;
full stability/commands/gallery/benchmark and F2/F3 acceptance still pending.
Update context before every commit and when ending; preserve Session B ownership.

---

## TinkerSpace migration partially applied - 2026-10-04

User selected regular Wi-Fi TinkerSpace instead of the phone hotspot and
confirmed local connection prompt success. Existing network-only firmware
compile/upload and Wi-Fi-fix authorization persists. No broader firmware scope.
USB ADB remains available; runtime STOPPED, no automatic restart/commit/push.
Existing HEAD d64f754f219d4b983a32bd87f740309fc2920e41.

Uno Q initially still on hotspot despite reported success; activated saved
TinkerSpace UUID aeab9e46-0448-450f-bd4e-fcd105990a37. Verified WPA2 2.4GHz
2462MHz association and DHCP192.168.1.99/24. S3 joined192.168.1.122,
MAC28:84:85:a1:85:ec, RSSI-52. C3 router DHCP IP UNKNOWN: do not guess.
User says both boards are close to router with clear antennas.

Both ignored SSID/password settings synchronized from active Uno Q profile,
without displaying password; unescaped extraction equality verified for both.
C3 destination IPAddress192.168.1.99; DHCP retained. Initial script expected a
macro instead of IPAddress and aborted C3 update; corrected and recompiled
before upload. Verified COM19 S3 / COM18 C3 chip and MAC identities. S3 compile
986425/56664 bytes and upload0/hashverified. C3 final1000105/37976 and upload0/
hashverified. Network-only C3 changes: removed prior8.5dBm transmit cap to SDK
default; disabled automatic reconnect, retained45s manual retries to avoid rapid
authentication loop. Neither change established successful router association.
No pins, capture, audio conversion or shared contract changes.

C3 initial/default-power logs repeatedly disconnect reasons2/201/36. Final50s
bounded-reconnect sample shows boot and three reason2 events, NO connectedIP.
No full audio probe run because peer address unknown. S3 initial router probe
HTTPstatus/stream timeout, 0frames; repeated probe0frames/62bytes, HTTPstatus
connecttimeout and streamreadtimeout. Captured report logs/router-camera-delivery.json
ok=false. Uno Q-to-S3 firstping753-904ms; later32-157ms, router53-151ms:
variable latency, not proof of a single AP or power cause. S3 connection succeeds
but usable HTTP stream not verified. All bounded serial readers/probes ended.

Root config.yaml and real runtime config still hold prior hotspot addresses:
DO NOT launch them on this network. Only ignored camera diagnostic config was
prepared using verified router IPs; no inferred C3 address. Complete all address
updates once C3 connects, then copy verified runtime config to Uno Q.
Next: resolve C3 WPA2 association (coordinate Session B/router administrator for
isolated association diagnostics), verify S3 HTTP recovery, then repeat concurrent
metadata delivery with C3 serial closed. Only after usable board connectivity
restart unrestricted user-command run. No phase/gate acceptance or stability
pass; prior136 software tests unchanged, not rerun for network-only work.
Secrets/helpers/builds/reports remain ignored; no private media saved to context.
Update handoff before every commit and when ending, preserving both sessions.

---

## Latest transport results; runtime stopped - 2026-10-04

Supersedes earlier pending-build and active-run records below. User reported
freshness interruptions again on the new hotspot. Vision remains STOPPED:
ADB pgrep app.main found no process. No automatic restart, commit or push.
Existing HEAD d64f754f219d4b983a32bd87f740309fc2920e41; no commit requested.

Under the user's explicit Session A Wi-Fi diagnostic/fix exception, compiled
and flashed both boards successfully (exit 0, flash hashes verified). C3 build
1000357 program / 37976 global bytes includes bounded ENOMEM/EAGAIN send retries
and preserved socket on transient failure. S3 build 986425 / 56664 includes
TCP_NODELAY on accepted HTTP sockets and bounded frame/send timing diagnostics.
Pins, camera acquisition/quality, microphone conversion and shared contract
unchanged. Secrets stay ignored. No media or credentials recorded here.

Final concurrent metadata-only sample with C3 serial CLOSED:
- C3: 842 valid packets / 30.260s = 27.83/s (expected 31.25), max gap 0.867s,
  20 gaps >100ms; zero malformed/other-peer packets and kernel UDP errors.
- S3: 74 frames / 25.427s = 2.91 FPS, maximum chunk gap 1.166s;
  status response 0.272s, RSSI -27. Report ok=true means finite HTTP delivery
  succeeded, NOT tracking stability acceptance.
- S3 timing while stream open: max camera frame wait 1ms, max network send wait
  1009ms then 1626ms. Closing sample showed 2524ms / result 0xb006; client was
  deliberately finite, so do not attribute that closing failure independently.
This separates camera acquisition from observed transport stalls. C3 previously
reported send-stage errno12/ENOMEM. Retry samples improved average delivery,
but remaining stalls prevent declaring the issue fixed or F2/F3 acceptance.

Uno Q powersave-OFF comparison did not improve delivery; actual radio restored
ON and saved profile to original default0. IPs: Uno Q172.20.10.2, C3172.20.10.4,
S3172.20.10.5. Laptop on Jasil; USB ADB forwards localhost:8080 to Uno Q gallery.
All bounded probes/readers ended. Prior software suite136 passed remains the
last result; not rerun for these network-only changes. Full19-command/features,
physical lights, smooth tracking, photo flow, phone gallery, benchmark, power
under load and standalone stability remain pending; no phase advanced.

Evidence: ignored logs/new-network-camera-final-timing.json,
logs/new-network-c3-final-timing.json, logs/new-network-s3-final-timing.log,
and final firmware compile/upload logs. Next: controlled comparison on a
non-phone 2.4GHz access point, with board destinations verified and the same
metadata probes; distinguish AP/transport behavior from board RF/power causes.
Do not silently change SSIDs or flash broader firmware. Restart freeform Vision
only when requested, with no timer and user-selected commands. Update context
before every commit; coordinate any further firmware work with Session B.

---

## New-network retry ended; deeper transport diagnosis - 2026-10-04

User reported same freshness interruptions. Verified PID14195 absent, UDP5005
listener absent, freeform result exit0. Runtime is STOPPED; no automatic restart.
Earlier active-run handoff is historical. User authorization for Session A Wi-Fi
diagnostics/fixes continues for this repair, with pins/capture/PCM contract fixed.

Uno Q NetworkManager permissions allow profile changes without sudo. Live
reapply of Wi-Fi powersave was unsupported; temporary saved-profile disable +
reconnect worked. Power-OFF concurrent sample: C3525/40.033s=13.11/s,maxgap3.126s;
camera36frames/21.366s=1.68FPS,maxchunkgap1.854s,status1.360s,readtimeout. No
improvement. Restoring profile default did NOT restore actual radio ON; corrected
by enabling3/reconnecting, then resetting saved profile to original default0.
Verified iw Power save ON and original profile default. No persistent power fix.

Precise C3 diagnostics exposed last_errno12/ENOMEM at stage send while receiver
active and no camera stream. Before retry:596/40.240s=14.81/s,maxgap1.092s,
0malformed/kernel receive errors; sender failures grew at UDPsend. Implemented
bounded transient ENOMEM/EAGAIN retry: failed sends only,2ms waits within16ms,
no duplicate after success,no offline replay; preserve existing socket for these
transient errors. Other errors still reset socket. Raw1024byte/16kHz/512sample
contract and microphone conversion untouched; producer log remains zero-wait.
Compile1000357 program/37976globals; upload0/hashesverified. Post retry sample
1120/40.495s=27.66/s,maxgap1.158s,0malformed/kernel errors. Send errors/retries
still occur. Improvement in this sample,NOT full audio stability or F3 pass.
Reader open during both errno/retry samples; serial-closed acceptance still needed.

Now compiling S3 network TCP_NODELAY accepted-socket experiment plus bounded
10s frame-wait/send-wait maxima to separate camera wait from transport delay.
No frame size,quality,sensor,servo,pin,endpoint or shared contract change.
This S3 build is NOT YET deployed/verified. Next: complete compile/upload and
40s metadata-only concurrent delivery + S3 timing capture; retain changes only
if measured useful. Latest verified board IPs UnoQ172.20.10.2,C3.4,S3.5. Laptop
previous hotspot,USB live URLlocalhost:8080/live; runtime remains stopped.
No commit/push,serviceactivation or full hardware acceptance. Update context
before every commit and when ending; preserve Session B records.

---

## New-network real-component run active; lag persists - 2026-10-04

User requested migration, all IP updates and another unrestricted real run.
User explicitly authorized two Session A exceptions: network-only secret/settings
build/upload, then Wi-Fi diagnostics/connection fixes. This does not authorize
unrelated firmware features/pins/contract edits or future phases. Corrected both
ignored SSIDs to verified laptop network, preserved user-entered passwords,
set C3 UNOQ_IP172.20.10.2, retained DHCP. Secrets remain ignored, not printed.
Verified chip/MAC/ports before upload. C3 final compile999979/37976 bytes,
S3 final compile986161/56664; final uploads exit0 with verified flash hashes.

S3 initially could not join. Added bounded disconnect reason/count reporting
(13 source lines; callback only updates counters, main reports at most2s).
Temporary S3 TX8.5dBm cap did NOT solve association; removed and flashed final
build with original transmit power. No other sketch behavior/pins/capture/audio
conversion/lights changed. New reporting revealed reason5 (ASSOC_TOOMANY,
access point unable to handle associated clients). Controlled test disconnected
ONLY Uno Q Wi-Fi while USB remained: S3 immediately joined172.20.10.5, whereas
Uno Q then failed rejoin. User says only laptop/UnoQ/C3 were connected. This
supports hotspot capacity in this observed setup, not a universal iPhone limit.
User moved laptop back to Jasil after Windows location policy blocked CLI switch.
Uno Q then rejoined successfully; all three board MACs reachable on new network.

Current verified board IPs: Uno Q172.20.10.2/28, C3172.20.10.4, S3172.20.10.5;
gateway172.20.10.1. Root config.yaml AND remote root/full-system config updated.
Laptop is on previous network and does not occupy new-hotspot slot. USBADB
662499217 forward tcp8080 -> UnoQ tcp8080 provides http://localhost:8080/live.
Application computation still entirely Uno Q; USB/laptop only console/live view.
Direct gallery on new network http://172.20.10.2:8080 (phone access unconfirmed).
ADB forwarding must be recreated after disconnect/device restart; no auto-start.

New-network delivery checks, serial monitors CLOSED, no capture/move/light:
Initial C3-only40.132s:388 valid packets,9.67/s,maxgap9.517s; not repaired.
After three boards could join, concurrent40s C3 + camera: C3993/40.010s,
24.82/s vs31.25expected,maxgap.639s,0malformed/kernel receive errors. Camera
20frames over13.065s,1.53receivedFPS,maxchunkgap1.197s,status1.106s; requested40s
ended early with2s readtimeout. Diagnostic okfalse. Changing network has NOT
eliminated delivery issues; these are network measurements, not CPU benchmark.
No claim of exact loss, smooth motion, WAV clarity, colours or full acceptance.

Requested app launched successfully, actual PID14195, UDP5005 owned by app,
--mic udp --seconds0 and real full-system config. USB /live and /live/frame.jpg
HTTP200; browser opened localhost live URL. Startup/calibration and camera sync
completed; repeated freshness warnings still observed. Accepted camera up at
08:04:15(board log clock); physical action not yet confirmed. No guided commands,
voice injection or automatic tracking; user chooses commands. Run continues
until user stops, no expiry or service activation. All diagnostics/readers ended.

Ignored logs retain final builds/uploads, serial association evidence, new-
network-camera-delivery.json and new-network-c3-delivery.json. Configuration
validation passed locally and on Uno Q. Prior136 software-test result unchanged;
not rerun for this firmware/network-only work. No commit/push requested. Existing
HEADd64f754; firmware/STATUS/context records updated under explicit exception.
Pending: user live feedback, residual stream/audio diagnosis, power under load,
full19-command/features/phone gallery acceptance, CPUbenchmark and standalone
acceptance. Next: observe freeform results or stop exact owned app on request;
never label network migration a stability pass. Refresh context before any commit.

---

## New-network uploads completed; S3 connection blocker - 2026-10-04

User explicitly authorized this Session A to compile/upload EXISTING sketches
and update network addresses only, overriding the normal Session B boundary
for this narrow task. No sketch implementation changed. Verified chips/MACs
before writing: C3 COM18 ESP32-C3 AZrev1.1/44:b1:76:17:f5:7c; S3 COM19
ESP32-S3 rev0.2/28:84:85:a1:85:ec. User-edited secrets initially did not match
laptop SSID exactly. Corrected SSID in both ignored headers to the observed
network, preserved user passwords, set C3 UNOQ_IP172.20.10.2. Both passwords
compared equal without printing values. DHCP1 retained; no guessed static IPs.

Both final builds succeeded: C3 999979 program/37976 globals; S3 984997/56656.
Both final uploads exited0, flash hashes verified and boards reset. Pins,
servo/camera/microphone conversion/light behavior/shared contract unchanged.
Source diff confirms neither sketch edited. Secret headers still Git-ignored.
One earlier successful upload had the nonmatching SSID; final uploads replace it.

Uno Q now on new iPhone network, DHCP172.20.10.2/28, gateway172.20.10.1;
laptop172.20.10.3. Uno Q fell back to old network once during uploads; manually
reactivated verified new profile and rechecked it remains new. Do not assume
future reconnections keep this DHCP destination; verify before later uploads.
C3 joined172.20.10.4; MAC confirmed by neighbour and serial boot. LightUDP5006
ready, audio destination172.20.10.2:5005. Ping averaged24ms in3 probes, but
sustained serial-CLOSED receiver40.132s got only388 packets (9.67/s), max gap
9.517s, zero malformed/other-peer/kernel receive errors. New network has NOT
resolved audio delivery. Source sender/network causal attribution still pending.

S3 has NOT joined; no confirmed new IP. Serial repeated Wi-Fi state changes
and E wifi:Set status to INIT after upload and after one authorized restart.
Camera/PSRAM/OV3660 initialization succeeds; latest boot reset_reason1 is
explicit tool reset, not a new inferred spontaneous brownout. No fresh BOD
message captured. User says iPhone Maximize Compatibility already enabled;
scan reports hotspot2437MHz. Password equality alone does not identify fault.
No extra connection behavior change authorized under network-only exception.
Asynchronous question asks user to authorize Wi-Fi diagnostics/connection fixes
here or hand remaining firmware issue back to Session B. Await decision.

Root config.yaml and ignored full-system config have UnoQ172.20.10.2 and
C3172.20.10.4. S3 field still OLD10.153.76.67; NOT ready for full runtime.
Launch console URL updated172.20.10.2:8080/live; app remains STOPPED, no full
new-network run or camera comparison claimed. Local config validation passed;
prior136 software tests not rerun for configuration/build-only changes.
Ignored logs hold build/upload/serial and new-network-c3-delivery.json metadata;
no speech WAV/media or credentials included in handoff. Serial readers closed.

No commit/push or service activation. Existing HEADd64f754. All physical
acceptance/CPUbenchmark pending. Exact next action: resolve Wi-Fi diagnostic
ownership, diagnose S3 association and C3 gaps, verify S3 IP by MAC/status,
finish runtime config/deployment, then run requested unrestricted live test.
Respect user no guided voice sequence and no time limit. Update context before
any future commit; preserve both sessions' records.

---

## New-network migration waiting for ESP32 uploads - 2026-10-04

User changed S3/C3 secrets and laptop network, requested Uno Q migration,
IP updates and retry. User explicitly confirms ONLY secrets files changed;
neither board uploaded. Old firmware therefore still runs old network settings.
No new S3/C3 address can be inferred from the edited files or old firmware.

Moved Uno Q using its existing saved new-network profile over USB ADB662499217.
Activation succeeded; actual DHCP address172.20.10.2/28, gateway172.20.10.1.
Laptop actual address172.20.10.3/28. Network identified from laptop connection
profile, no stored passwords read. Initial Unicode profile-name command failed;
retry using verified connection UUID succeeded. App already absent before switch.
Read-only discovery .4 through .14 found no confirmed S3/C3 MAC. C3 COM18 counters
continue from prior firmware. Serial reader bounded and closed after check.

Updated only Uno Q address in config.yaml and ignored full-system config;
launcher live URL is now http://172.20.10.2:8080/live. Existing S3/C3 fields still
contain OLD network addresses and are NOT migration-ready; do not run app yet.
No firmware files modified or uploaded. Session A ownership exception requested
asynchronously: either user authorizes network-only updates/build/upload of
existing sketches, or Session B performs them. C3 UNOQ_IP must be172.20.10.2.
New IPs must be verified by board MAC/boot output before runtime config update.

Vision remains STOPPED. No lag comparison or full acceptance run on new network.
No service activation, commit or push. Existing HEAD d64f754. Software freshness
fix and prior136-test result unchanged. Exact next action: resolve firmware
upload ownership, upload updated network configuration to both boards, discover
actual S3/C3 IPs, update and deploy runtime config, measure both delivery paths,
then launch real-component/freeform live run with no time limit. No guided voice
commands; preserve Session B shared records and mandatory pre-commit context.

---

## User-requested real-component restart - 2026-10-04

User said run again. Verified no active app or Wi-Fi comparison and UDP5005
free; Uno Q power saving remains ON. Prior sudo comparison ended before the
off comparison, so no repair or comparison success is inferred. Restarted
existing freeform real-board runner over USB ADB662499217 with UDP microphone,
S3 camera and C3 lights, seconds0 (no expiry). Actual app PID13298; audio UDP5005
listener owned by that process. Live page HTTP200; browser opened at
http://10.153.76.45:8080/live. No guided commands or injected voice/movement.
C3 logging repair is flashed per Session B; sender/network delivery issues from
previous measurements remain unresolved. Software freshness race fix deployed.
No firmware edits, service activation, commit or push. Earlier 136-test result
unchanged, not rerun for launch. Full physical acceptance/benchmark pending.
Next: review user's freeform results or stop app when requested. Update context
before any commit; preserve separate Session B records.

---

## Camera and microphone repair investigation - 2026-10-04

User authorized fixing delivery issues. Vision remains stopped; no movement,
capture, light command, firmware modification, flash or service activation.
Session A ownership remains in force. Latest Session B handoff confirms the C3
queued-logging repair WAS FLASHED successfully on COM18. Earlier Session A
notes saying unflashed are superseded. User confirms hotspot close and awake,
battery saver off. Uno Q remains 10.153.76.45, S3 .67, C3 .243; MACs verified
through Uno Q neighbours. ADB serial 662499217; C3 COM18 is present again.

Actual stopped-app measurements after repair:
- C3 serial-closed 20.081s: 601 valid packets, 29.93/s, max gap 1.070s,
  zero malformed/other-source/kernel receive or checksum errors.
- S3 stream-only 21.095s: 87 frames, 4.12 received FPS, max chunk gap .937s,
  status latency .534s, RSSI -39, uptime 788s. No HTTP errors. Diagnostic ok
  means delivery occurred, not stable tracking or physical acceptance.
- C3 active receiver + serial open 40.057s: 1036 valid packets, 25.86/s,
  max gap 1.420s, zero malformed or kernel receive errors. Sender counters
  increased from sent15353/errors6147 to sent16076/errors6363 across three
  10-second reports, then sent16389/errors6363 on the next report. Send failures
  persist with an active destination; not simply a missing receiver or old
  blocking producer logging. Their exact stage/errno remains unknown.
- Uno Q ping averages: C3 380ms (max1072), S3 373ms (max829), hotspot130ms.
  Laptop also sees C3 delays up to1119ms and one timeout in five probes.
  Strong RSSI does not establish a responsive path. Network/firmware attribution
  still unresolved; no power problem inferred solely from these measurements.

Temporary Wi-Fi comparison launched in a local console; sudo authentication
is pending. No power setting changed yet. Baseline 633/20.011s =31.63/s,
max gap .620s, zero receive errors. It will test power saving off and restore
original ON through an EXIT trap; no permanent profile edits. First attempt
failed due to CRLF in an ignored script; corrected LF and restarted. Existing
result JSON from first attempt is stale while new test waits. No secrets saved.

Evidence is metadata under ignored logs/: c3-repair-receiver.json,
c3-repair-sender.log, repair-camera-baseline.json, unoq-wifi-repair-console.log.
Software freshness race fix from preceding turn remains deployed; 136 tests
passed then, not rerun here because production source is unchanged this turn.
Current HEAD d64f754f219d4b983a32bd87f740309fc2920e41. No commit/push requested.
Acceptance and benchmark remain pending. Next: complete authenticated network
comparison, evaluate measured effects, and report any remaining sender firmware
fault to user for Session B. Do not increase freshness/buffer limits to hide gaps.

---

## Camera-ready freshness race fixed; runtime remains stopped - 2026-10-04

User asked what's happening after repeatedready/unavailable logs and^C.
Explained .5sfreshness cutoff andgenuine deliverygaps;Voskloadmessages normal.
Found software race:control computedfresh beforeCameraRecovery.poll,which can
blockon/status;poll thenannouncedready andcontrolused pre-waitframe/boolean.
SlowHTTP can make that oldsnapshot stale before recoveryannouncement/movement.

Fixed only SessionAsoftware:CameraRecovery acceptsoptional freshness_check,
revalidates aftersuccessful/status beforeonline/ready;failedfreshness backs off
andretainsreconnect. Mainpasses currentstreamfreshness callback andrereads latest
frame afterpoll beforetracking/control;immediatelyblocks staleframes. Original
.5s cutoff and networktimeouts unchanged. No firmware,gain,confidencechange.
Two regressions cover slowstatus withexpiredframe(no ready) andcontinuingnew
frames(legitimate recovery). Full136 pytest pass in11.22s. This is softwarefix,
not proof hardware/networkdelivery repaired. Genuine longgaps still causeoffline.

Verified priorrun exited0 andno appactive;deployed onlyapp/main.py andapp/runtime.py
viaUSBADB662499217 to/home/arduino/Vision,remote py_compile passed. No apprestart
or physicalmovement/capture triggered. Latest activeJSON nowstopped,lastPID12664.
Next user's authorized retry can exercisefreeformcommands;review whether false
ready/stale alternation improved andactual frame/audio stability. C3repairnot
flashed,S3load/restart issue,all19physicalacceptance/CPUbenchmark remainpending.
No commit/push requested for thisfix;source/context dirty. Mustupdatecontext before
any futurecommit. Preserve SessionBfirmwareandsharedrecords;no guidedtestcommands.

---

## User-requested retry running - 2026-10-04

User said lets try again after faileddeliverymeasurements. Confirmed UnoQUSB
662499217,no existing runtime/audio diagnostic;archived priorconsolelog and
restarted existing realcomponent/freeformrun withseconds0. ActualPID12664,
/liveHTTP200;opened browserliveview. Camera synchronization/recovery logged but
freshnesswarningsalreadyrecurring. No firmware/power/network/sourcefix applied;
this is retry,not evidence underlyingissuesresolved. No commandsequence/instructions
imposed. No serialreader workaround available unlessESPUSBconnectionsreturn.
CurrentknownIP/configunchanged;C3repairstillnotflashed;physicalacceptance,
standalone,CPUbenchmark remainpending. Await user's results/stop request.
No commit/push;mandatorycontext refreshed;Session A nevereditsfirmware.

---

## Reported live outage investigated; test remains stopped - 2026-10-04

User supplied sustainedS3connecttimeout from07:13:40..07:15:44(boardclock),then
rapidfreshnessoutage/recovery and missingC3audio>5s at07:16:45;runended^C.
Verified appabsent,resultexit0;no restart made. User explicitly confirmed NO
boardunplug/restart orhotspotchange;they stayedpowered. S3/status later200,
uptime146/reset_reason1 confirms recent spontaneousrestart. Historicalbrownouts
exist,but currentcause cannot be confirmed withoutfreshSerial. S3USB/C3USB ports
stillabsent;UnoQUSB662499217/wlan0IP10.153.76.45 available.

Ran read-only camera andC3UDP diagnostics concurrently onUnoQ withappstopped,
no motion/capture/ACK/light commands. Camera93frames/21.463s,4.33receivedFPS,
maxchunkgap1.671s,statuslatency1.338s,RSSI-41,uptime186,errors[]. Its oktrue means
finiteHTTP/streamdelivery,NOTstabletracking;gaps exceed .5sfreshnesswindow.
C3only38validpackets/20.351s,1.87/s vs31.25expected,maxgap14.374s,0malformed,
0otherpeer,0kernelreceive/checksum/buffererrors. This is severe delivery failure;
not voicegrammar or exactpacketlossmeasurement. Concurrentradio streams mean
network/firmware/power causal attribution stillrequires controlled evidence.
Stored ignoredlogs/real-s3-outage-check.json,c3-after-outage.json andconsoles.

C3compiled nonblockingloggingrepair remainsUNFLASHED per latestSessionBhandoff.
No firmwarechanges/flash performed bySessionA. Updated issuehandoffs withlatest
evidence. Nextdependency:SessionBrepairdeployment andnewclosed-monitorpacket
acceptance,plus S3reset/power/network diagnosis withfreshSerial andloadmeasurement.
Do not increasefreshness/readtimeout orweakenacceptance to maskfaults. No full
19command/features acceptance claimed;CPUbenchmark/standalone gates pending.
Honoruserfreelychosencommands/no guidedsequence oncehardwaredeliveryready.
Context updated;no newsourcechange/tests/commit/push;current softwared64f754.

---

## Freeform runtime restarted and verified - 2026-10-04

User said lets run again. Confirmed priorapp absent and USBUnoQ662499217 active,
archived prior consolelog,launched same realboard/freeformmanualstoprunner.
First startup receivedCtrl+C during Voskmodel loading and exited130;trace's
Voskdestructor _handle error was after interruptedconstruction,not missingmodel.
Verified model files present. Retriedonce;actual app nowrunningPID11568 with
app.main/full-systemconfig/UDPmic/seconds0. Gallery/live HTTP200;camera-ready
control synchronization seen,with recurring shortfreshness interruptions.
No sourcechange or firmwareflash;no serialreaders(activeESPUSBports stillabsent).
Do not confuse stale freeform-result130 from firstattempt with actualactivePID;
ignoredlogs/freeform-active.json records latestactivecheck. Not a stability pass.
User chooses commandsfreely;no instructions/guidedsequence. Existingcoverage,
power/load/C3repairflash/physicalacceptance/benchmark pending states preserved.
No commit/push;context refreshed. Nextreview user's results or stop request.

---

## Freeform test stopped at user request - 2026-10-04

User said stop. Matched exact owned full-system appPID10145 and sentSIGINT;
verified process absent and gallery8080/audio5005listeners gone. Serialstopmarker
written;no ESP32serialreaders were active thisrun. No restart authorized.
Freeform result/console logs ignored;physicalacceptance stillunconfirmed.
Accepted uniquecommands observed:camera stop tracking, camera track person, camera centre.
Savedphotoevents:none.
Commandevents alone do not prove physicalactions or full19-commandacceptance.
Camera freshness interruptions occurred;currentcause notconfirmedwithoutSerial.
Latest source from committedrecoveryversion deployed;C3repairstillnotflashed,
powerload/standalone/fullacceptance andCPUbenchmark remainpending.
Next:review user's feedback before any further run;respect no guidedcommands.
No source/firmwarechanges,commit/push. Context refreshed before ending.

---

## User-directed full-system test running - 2026-10-04

User requested all commands/features but explicitly NO instructions or guided
sequence;user will choose commands freely. Honor this preference. No expiry.
Read newest appended cross-session handoff:powerbank feeds S3USB,servos from
S35V/GND;this supersedes older laptop-only topology. C3logging repair is compiled
but NOT flashed;service prepared/inactive;134test/syntheticrecovery evidence
was from the other session,not rerun by Session A here. CurrentHEADd64f754.

Verified UnoQUSBADB662499217,wlan0IP10.153.76.45;S3/status200 at10.153.76.67,
90/90,idle,uptime2905,RSSI-49. C3neighbour10.153.76.243 REACHABLE and actual
spoken command later accepted. COM18/19 are currently absent;only UnoQCOM20
present. No serial reader workaround could start;no guessedport or firmwareflash.
User reauthorized physical test;powerload/newC3firmware acceptance not inferred.

Deployed latest committed SOFTWARE app/*.py and gallerytemplates only to
/home/arduino/Vision over trustedUSB (ignored freeform-app.tar.gz21KB). No models,
photos,firmware,serviceactivation or secrets touched. Remoteconfigcheck passed.
Opened Vision - freeform full system test;existing runner executes app.main
UDPmic/realboards/seconds0. Current appPID10145. Opened browserlive URL
http://10.153.76.45:8080/live;page/frame200. Latestsoftware toleratescamera outage;
voice/gallery running,control synchronization/recovery logged repeatedly.

Early observation:camera freshness warnings14 with quickcamera-ready recoveries;
do NOT call currentrun stable or infer brownout without newSerialevidence.
Accepted camera stop tracking07:04:16.598(boardclock),1of19unique supported
commands observed in initialcapture;no newphoto yet. Remaining commands are
unrun/unobserved,notfailures. Coverage saved ignoredlogs/freeform-command-
observations.json;consolelogfreeform-vision-console.log records events/errors.
No user's commandorder imposed,no automaticmoves/shoot/voiceinjection.
App staysrunning while usertests;no timer or serviceautostart introduced.
Next:review user's failures/results and evolvingcommandcoverage;record physical
servomotion/NeoPixel/photo/phonegallery observations separately. Completeall19
onlywhenactuallyobserved;standalone/benchmark/gates stillpending. No commit/push
thisturn;context refreshed. Session A nevereditsfirmware under renewedinstructions.

---

## Complete-project publication preparation - 2026-10-04

User explicitly requested update contexts then commit and push EVERYTHING.
This authorizes publication of all existing software,deployment,firmware,CAD,
editor and context changes; no new firmware implementation or future phases.
Existing HEAD before this commit:bf898850ed1fe0a0fc68a9f5c0e6a6a948f1087b
Intended commit message:feat: publish live tracking, C3 firmware and enclosure models
Do not invent the resulting commit hash;Git log is authoritative after publish.

Scope:read-only live annotated /live + /live/frame.jpg using UnoQ's existing
tracking snapshot,gallery link;new gallery tests;Phase5 network diagnostic and
quote-safe runner/current-IP deployment docs;user board config;existing C3
voice_unit and Wi-Fi diagnostic/checker/docs/context;ESP32C3/S3 editor setup;
enclosure OpenSCAD,9 STL exports,previews and validation;durable issue handoffs.
Root context records below preserve separate firmware/CAD histories. Root current
handoff supersedes older firmware notes claiming no receiver tests had yet run.
No credentials,private media,model/toolchain archives or ignored runtime logs.

Editor publication also includes .vscode/README.md and refresh_firmware_intellisense.py;
refresh ran successfully and mapped3original sketches to their actual compiler commands.
Generated database stays ignored;no credential contents read.

Fresh commit checks:129 pytest tests pass (7.56s);bash syntax for Phase5 runner
passes;normal Git diff --check passes. C3 production sketch compiled999841bytes
program/37976globals;Wi-Fi diagnostic953875program/36152globals,exit0 for both,
no hardware upload. All9 existing STL meshes pass standard-library validation.
No credential scan matches;both ignored secrets.h and private WAV/JPEG confirmed
excluded. HEAD/origin main synchronized before commit. Source tests/compilation
are not physical hardware acceptance;no phase/gate declared complete.

Latest live run is STOPPED:app log ends^C,result exit0,no app process found via
USB;owned serial reader26616 absent. User said everything powered from laptop.
Current known IPs S3 10.153.76.67,UnoQ 10.153.76.45,C3 10.153.76.243;reverify DHCP
before future run. Full application runs on UnoQ;live URLhttp://10.153.76.45:8080/live.
Manual run has no timer;Ctrl+C stops it. Runtime-local launch scripts are ignored,
not part of reproducible firmware fix;README documents normal runtime command.

Confirmed blockers:repeated S3brownouts after servo motion (power topology and
under-load voltage need hardwareteam);C3 USB logging suspected to stall audio
when serial reader closed (open31.41packets/s vsclosed2.265s gap). See
HARDWARE_POWER_ISSUE.md and FIRMWARE_AUDIO_ISSUE.md. Original five-second C3
checker failed42.4% rate shortfall. All8 light states were sent but physical
colour/clear-WAV confirmation not received. Live direction/track/shoot accepted,
photosIMG_0001/0002 saved in actual logs;phone-new-photo/fullmotion smoothness
unconfirmed. Spoken camera stop tracking accepted at least once after initial
recognition complaints. Network14.45FPS is NOT CPU benchmark;UnoQ benchmark
still unrun. Full mock/hardware acceptance remains pending despite publication.

Next resume:read this handoff and issue docs;resolve S3power and nonblocking C3
logging through hardwareteam/SessionB;verify gates,then full real-component
tracking/photo/physicallights/phone-gallery and actualCPUbenchmark. Do not
restart automatically or implement later phases merely because commit pushed.
Update context before every future commit;preserve other sessions' work.

---

## Laptop-powered restart explicitly requested - 2026-10-04

User confirmed everything powered from laptop and explicitly requested run again
after brownout finding. Restart is an authorized diagnostic continuation,not
hardware power acceptance or a fix. No supply/firmware/threshold change.
Confirmed UnoQ USBADB662499217,no existing app receiver. S3/status returned200:
90/90,idle,uptime84,reset_reason1,RSSI-44 after recent reboot. Actual S3 USBCOM19
absent;COM20 PnPVID2341/PID0078 is UnoQ,not guessed S3 replacement.
Initial both-port reader PID28116 failed opening missingCOM19 and disposed C3.
Ignored serial helper now requires confirmedC3COM18 and optionally opensCOM19
only if present. New readerPID26616 successfully openedCOM18 only;no timeout.

Started existing no-time-limit real-component UnoQ app. Actual Ready06:05:35.476
boardclock,backgroundRMS42.6,accepted camera up06:05:39.694. Verified live page200
and frame200;opened http://10.153.76.45:8080/live. StartsIDLE unless user commands
tracking;no automatic track command injected. Ctrl+C in Vision console stops
app and signals reader. Keep C3USB attached for current logging workaround.

Confirmed S3brownout issue remains unresolved;laptopeverything supply does not
establish adequate servo load power. Cap installation/under-load voltage still
unmeasured. If resets recur,report hardwareteam;do not claim standalone/full
acceptance. Latest source129tests unchanged;only ignored runtime helper adjusted.
No commit/push or firmware changes. Context refreshed with user override/state.

---

## S3 brownout confirmed; runtime stopped, hardware power check required - 2026-10-04

User reported recurring camera stream/move timeouts. Read actual S3 COM19 log:
repeated E BOD:Brownout detector was triggered immediately after streaming/moves,
followed by ROM boots and camera/WiFi reinitialization. Laptop /status timed out.
This confirms low-supply resets; specific source/cable/connection/load cause
requires measurement. Espressif official fatal-error docs checked; diagnostic
handoff context/HARDWARE_POWER_ISSUE.md created with evidence and Gate A checks.
Don't mask brownout by disabling protection or extending network timeouts.

Uno Q app had already exited:log^C,result exit0,no Pythonapp or8080/5005listener.
Wrote serial stop marker;reader PID5200 also no longer present after cleanup.
No restart,no firmware/application/power-setting changes. Prior live page could
show stale camera frame while reconnecting; do not infer camera alive from200.
Voice recognized track person;end-to-end camera tracking failed under load.
Earlier hardware readiness confirmation superseded by actual failed power test.

Asked actual S3/servo power source,USB cable,servo5V topology and470uF capacitor
installation. Await user/hardware-team reply,then correct feed and measure S3
5V under both-servoload (project~4.6V criterion),repeat controlled reset-free
camera test before tracking. Sharedground/freebracket/polarity checks per plan.
No new automated test needed (source unchanged),latest129pass. Hardware full
acceptance/benchmark and C3 standalone logging fix still pending. No commit/push.
Context refreshed; preserve firmware/CAD/editor changes.

---

## Vision restarted at user request - 2026-10-04

User said lets run it again. Confirmed USB ADB662499217 connected,no existing
app/audio diagnostic,COM18/COM19 present. Archived prior run log/result files
under ignored timestamped logs. Cleared stop marker,restarted owned persistent
serial reader PID5200 (COM18C3+COM19S3,both opened),then existing no-time-limit
UnoQ app with real-board full-system config and live annotated gallery.

Actual Ready05:55:01.317(board clock),backgroundRMS48.8,accepted camera track
person05:55:05.435. Verified /live200,/live/frame.jpg200 image/jpeg;opened
http://10.153.76.45:8080/live in user's browser. No timer. Ctrl+C in Vision -
RUNNING until Ctrl+C stops app and marks serial readers to exit. Keep USB attached
for logging workaround. No firmware/application changes,new tests,commit/push.
Earlier full129tests remain latest source verification. Standalone logging issue,
user-observed complete acceptance and CPU benchmark remain pending. Previous
run did accept camera stop tracking at least once. Context updated before ending.

---

## Vision stopped at user request - 2026-10-04

User explicitly said stop process. Identified exact owned Uno Q app PID6107,
validated command line app.main/full-system config/UDP/seconds0,then sent SIGINT
for graceful cleanup. Wrote ignored logs/vision-stop-serial.request so owned
serial workaround exits. Reader PID22888 had already exited; its result reported
ReadExisting port closed. No serial reader remains; do not claim this runtime
was stable after USB disconnection. No other app/service/board stopped/reflashed.

Verified appPID absent and listeners inspected after shutdown;gallery8080 and
appUDP5005 confirmed closed;app result exit0. No restart authorized. Keep live page/source changes
and photos; no commit/push. Next session reads stopped state,addresses/current
hardware again before launching. Shutdown review found accepted "camera stop tracking" at05:46:18.586(board
clock);recognition did succeed at least once. User-observed stop behaviour and
standalone logging issue remain unverified;camera timeouts recurred before stop.
Hardware full acceptance/CPU benchmark remain pending.
Local full129tests passed for live view previously. Context refreshed; preserve
firmware/CAD/editor changes and before-every-commit maintenance rule.

---

## Live annotated browser view deployed and verified - 2026-10-04

User requested visible live camera/tracking and reported no response to spoken
stop tracking. Correct exact phrase remains "camera stop tracking". Existing
logs had no accepted stop command; no voice threshold/gain change or speech fix
claimed. Existing state test covers transition to IDLE when command accepted.
User then requested restart with live visual; implemented requested view only.

Added /live browser page and /live/frame.jpg to existing Uno Q gallery8080.
Uses read-only callback from the existing control/display snapshot,without
opening another S3 stream or running detection on laptop. JPEG includes green
box,mode,pan/tilt,dx/dy,search/stopped/reconnect indication. Page polls one request
at a time every250ms,backs off when hidden,retries unavailable camera. Routes
return404 without provider,503 while no frame,no-store caching. Gallery root
links live view. No browser control/movement route added.
Files:app/main.py,app/gallery/server.py,templates/index.html,templates/live.html;
new tests/test_live_gallery.py. Full129 tests pass (7.49s),remote py_compile passed.

Prior manual-stop app/monitor had already ended (no Python receiver or owned
reader present); cause not established. Preserved prior app log, deployed only
runtime source/templates over verified USB ADB,then restarted no-time-limit app
and serial workaround. New monitor PID22888,COM18/C3+COM19/S3. Same stop marker
and Ctrl+C console cleanup;no app/monitor timeout. No firmware changes.
Actual remote Ready05:40:53.796,accepted track person05:40:57.713. Live page200,
JPEG200,image/jpeg,decoded320x240. Visually inspected actual frame:greenperson
box,TRACKING,pan43/tilt93,dx-0.04/dy-0.12. Opened user's browser to
http://10.153.76.45:8080/live. Also accessible on phone same network.
Image/private evidence ignored logs/vision-live-preview-{check.jpg,result.json}.

Next: user says camera stop tracking,pause;watch IDLE and box disappear. If no
recognition,response remains voice issue; don't claim it fixed from visual UI.
Original user physical full-test/phone-new-photo confirmation,CPU benchmark and
standalone USB-logging fix remain pending. App continues until user Ctrl+C in
Vision - RUNNING until Ctrl+C. ExistingHEADbf89885;no commit/push. Context updated
before ending and must be refreshed before every future commit. Preserve separate
firmware/CAD/editor work and shared records.

---

## Vision running without time limit; manual stop only - 2026-10-04

User explicitly requested Vision keep running until they shut it down. Replaced
timed600s live launcher with ignored logs/run_vision_until_stopped.sh using
--seconds0; same real-board config,app executes on Uno Q via USB ADB662499217.
No startup service or future-phase implementation. Prior app had already ended
(no Python receiver/process found); old owned C3 serial reader PID27744 stopped.

New owned hidden serial monitor PID20228 opens COM18(C3) and COM19(S3),drains
both logs without a time limit; DTR/RTS false. S3 added because earlier live
app recorded stream/move timeouts and firmware stream handler also prints
periodically. This is a diagnostic workaround,not a proven S3 firmware fix.
No firmware changes/flash. C3 suspected blocking logging remains Session B issue.
Reader loops until ignored logs/vision-stop-serial.request exists. Visible app
console Vision - RUNNING until Ctrl+C writes that marker in finally on app exit.
App and serial readers have NO elapsed-time expiry. Manual Ctrl+C in that console
is the requested stop action; force-closing windows may bypass cleanup,so verify
remote process/monitor if shutdown uncertain. Keep USB cables attached for this
workaround. No headset/laptop microphone/camera mocks used.

Actual app log:Ready05:32:23.656(board clock),backgroundRMS20.0;recognized camera
track person05:32:25.766. C3 actual Serial:ready,heard,tracking; packet send counters
96942->97255,send_errors7151 unchanged. S3 Serial:10.153.76.67,HTTP ready,stream
open socket55,move accepted pan90/tilt89. This proves startup/command delivery and
control request,not user-observed smooth tracking/photo/full acceptance.
Ports and board config unchanged:UnoQ10.153.76.45,C310.153.76.243,S310.153.76.67,
galleryhttp://10.153.76.45:8080. Private logs ignored:vision-until-stopped-app,
vision-COM18/COM19,monitor-result and app-result. No timed watchdog introduced.
Next: user uses app,tests shoot/new phone photo and other commands; assistant
reviews reported errors/logs. CPU benchmark/full standalone acceptance remain
pending. No commit/push;HEADbf89885. Context refreshed before ending.

---

## Full real-component app Ready on Uno Q - 2026-10-04

User explicitly requested all-components full test now. Started existing app on
Uno Q via verified USB ADB662499217; no SSH password needed. Uses ignored remote
logs/config.full-system.yaml:real S310.153.76.67,real C310.153.76.243,UDP5005 mic,
UDP5006 NeoPixel,normal remote/home/arduino/Vision/photos,gallery8080. No mocks,
laptop mic or Bluetooth headset. User hardware readiness previously confirmed.
App logged calibrated backgroundRMS86.7 and Ready at05:27:42 board clock.
C3 Serial reports light ready and313successful sends between10s reports with
send_errors7151 unchanged in sampled startup. Light receipt does not confirm
physical colour. Actual voice/actions/photo acceptance remains pending.

Disclosed temporary workaround:owned hidden PowerShell serial reader PID27744
holds COM18 open/drains status logs,DTR/RTS false,no reset/flash. Bounded1200s.
Visible console Vision - ALL REAL COMPONENTS on Uno Q runs app600s; its finally
stops owned monitor after app ends. Logs/full-system-live-usb-{app,result},
serial-monitor log/result are ignored. Ctrl+C in visible console ends early.
Do not force-close window without checking app/monitor cleanup. No standalone
pass while serial-reader workaround required; Session B logging fix remains.

Asked user to test track person with movement,shoot/new photo from phone,
stop tracking/manual left/right/up/down/centre,burst,timer,sleep/wake and report
physical light behaviour. User response pending. Laptop gallery read-only check
recorded separately in logs/full-system-gallery-readonly.json; it does not prove
phone access or a new capture. CPU benchmark still pending; no phase completed.
No firmware edits,no gain/threshold changes,no commit/push. ExistingHEADbf89885.
Context updated before ending; preserve firmware/CAD/editor work.

---

## Serial-open/closed comparison identifies likely audio stall - 2026-10-04

User said ready with hotspot awake and nearby.20s result533packets/20.02s,
26.62/s,maxgap2.374s; not reliable. Then concurrent40s receiver+C3 serial
capture:1258packets/40.056s,31.41/s,maxgap0.555s,0malformed/kernelerrors;
C3 counters increased313every10s,send_errors7026 unchanged. Serial reader
closed after capture and port disposed. Repeat closed:576packets/20.024s,
28.77/s,maxgap2.265s. This open/closed difference strongly suggests USB status
logging stalls the audio task. Source review finds audioTask Serial.printf
counter report every10s and installedHWCDC write can wait20x100ms under host
backpressure. Root cause inference needs firmware fix+controlled retest to confirm.
Open-monitor maxgap0.555s still exceeds normal32ms playout and does not establish
speech clarity/full acceptance. No gain/confidence/buffer changes.

Created context/FIRMWARE_AUDIO_ISSUE.md with exact evidence and Session B action:
nonblocking USB logging independent of audio delivery; preserve shared contract;
compile/upload workflow and closed-monitor/power-only acceptance. No firmware
edits or flash. Asked user whether to continue full hardware diagnostic with
serial monitor open temporarily or have firmware session fix first. Await reply
before dependent live test. Both are pending; don't claim standalone pass.
Original UnoQ powersaveON remains restored. All measurement JSON/private logs
ignored. No mock mic/headset used. No new lights/capture during these checks.
ExistingHEADbf89885;no commit/push. Context refreshed.

---

## Uno Q power-save comparison did not fix delivery - 2026-10-04

USB diagnostic completed exit0; iw was installed for inspection. Actual baseline
power-save ON:506valid packets/20.03s,25.26/s,maxgap2.494s. Temporary OFF:508valid/
20.011s,25.39/s,maxgap2.121s. Both had zero malformed and UDP receive/checksum/
buffer errors. Difference does not resolve delivery gaps; don't claim a fix.
Baseline/off saved ignored logs/c3-udp-power-{baseline,off}.json. Original setting
restored by trap and independently verified /usr/sbin/iw:Power save:on. No saved
profile/service/firmware changes. Private earlier WAV remains ignored.

Read-only iw link/station:Uno Q associated to Jasil on2412MHz,signal-38dBm,
average-36dBm,72.2Mbps reported RX,connected3990s,beacon_loss0,rx_drop_misc309
cumulative. Cumulative counters do not prove current gap cause. Collected25s iw
events to logs/unoq-wifi-events.log; outcome must be reviewed, not inferred.
Next controlled test requested from user:keep hotspot phone awake with settings
visible and place phone beside Uno Q/C3; reply ready before receiver retest.
This tests hotspot/location conditions without firmware/credential changes.
Full app remains stopped; voice/light/full-system acceptance and CPU benchmark
still pending. Do not loosen rate threshold or treat camera success as full pass.
No commit/push; context refreshed; preserve firmware/CAD work.

---

## Receiver gaps confirmed; Wi-Fi comparison opened - 2026-10-04

User completed20s receiver diagnostic; local logs/c3-udp-diagnostic.json confirms
502valid packets in20.41s (24.6/s vs31.25expected),0malformed/other-source,
max gap2.402s,28gaps>100ms,two1s bins withzero arrivals,RMS172.85,peak728.
Kernel UDP InErrors/RcvbufErrors/InCsumErrors/MemErrors all0; NoPorts3 during
this interval is not a receive-buffer error. Board load0.07/0.10/0.09,no existing
UDP5005 owner shown. Data supports delays/loss before application UDP receipt;
Wi-Fi/driver/hotspot buffering is a hypothesis, not proven root cause. Raw packets
lack sequence numbers; exact loss unavailable. Full integration still blocked.
Private earlier WAV downloaded under ignored logs/full-system-mic.wav; clarity
and physical light behaviour still require actual user observation.

Verified existing USB ADB target662499217 is connected,accountarduino,hosttinker,
wlan0IP10.153.76.45. iw utility absent from PATH and normal sbin candidates;
sudo requires local password. No profile/network changed by read-only checks.
Opened Vision - Uno Q Wi-Fi comparison via USB (logs/unoq-wifi-power-console.ps1).
Script installs only iw if missing using local sudo entry, reports link/power
state,measures20s baseline. ONLY if power save is on, temporarily disables it,
measures20s comparison and restores on via EXIT trap. No profile persistence,
service restart,firmware change,movement,lights,new audio recording or app run.
If interrupted forcefully before trap executes, check actual power state; do
not assume restore. Bash syntax passed. Outcome pending local console completion.
Next user action: Linux sudo password in that console only, then inspect pulled
baseline/off JSON and log; do not infer improvement before actual comparison.
Keep original full-system checker acceptance thresholds; don't mask delivery gaps
by increasing jitter buffering. No commit/push; HEADbf89885. Context refreshed.

---

## Full-system audio check failed; targeted diagnosis running - 2026-10-04

User supplied actual C3 checker failure:90valid packets,0malformed over5.00s,
2.88s PCM,RMS126.2,peak416,estimated rate shortfall42.4% (>20% fails). All8
light commands were sent; physical colours and recording clarity are still
unconfirmed. The full app did NOT launch. Receiver arrival failure means real
voice acceptance/Gate B testing remains incomplete despite hardware readiness.
Camera automated checks passed previously; whole-system pass must not be claimed.

Read production C3 Serial on confirmed COM18 with DTR/RTS false; no flash/reset,
closed/disposed port afterward. Counters65412,65725,66038,66351,66664:313successful
sends between each10s firmware report (expected31.25/s). send_errors6011 unchanged
throughout; historic errors exist but none newly observed in this capture.
RSSI-44..-46. Successful UDP send is not proof of receiver delivery; these samples
were later than failed5s check and do not establish its cause. Serial saved in
ignored logs/c3-audio-sender-counters.log. No firmware edits or gain changes.

Opened Vision - C3 audio rate diagnostic (ignored logs/c3-network-diagnostic-
console.ps1). User authenticates locally with strictly verified board host key.
Uploads20s read-only receiver checker: counts valid/malformed/other-source,
per-second rates,arrival gaps,RMS/peak,kernel UDP counters and receiver load.
Refuses concurrent app/demo_voice. No raw recording,new photos,lights or movements.
Copies summary and already-created private WAV back to ignored laptop logs.
Next: user enters passwords,speaks near INMP441; inspect summary to distinguish
sender/network/receiver behaviour. Do not weaken packet-rate acceptance or
confidence threshold to bypass failure. Firmware bugs go to Session B/user.
No application changes,no commit/push; HEADbf89885. Context refreshed.

---

## Full hardware acceptance launched - 2026-10-04

User answered "yeah all good" to the explicit Gate A/B hardware and F2/F3 readiness
question. Treat this as affirmative user hardware confirmation, not agent-run
physical evidence. Earlier waiting-for-gate entry is superseded for this requested
test. No firmware modifications or future-phase implementation.

Existing firmware camera checker ran against real S3 10.153.76.67 and exited0:
status,85-95degree pattern/readback,QVGA,servo responsiveness while streaming,
2048x1536 capture141451bytes,identical held retry,ACK release,same stream survival
and fresh stream all PASS. Capture10.96s,retry5.81s; these latencies are recorded,
not a throughput benchmark. Restored90/90. Physical smoothness/image quality
still user-observed pending. JPEGs private/ignored logs/full-system-camera.
C3-only UDP recognition diagnostic ended exit0; audio levels observed, command
recognition remains unconfirmed from existing logs.

Opened logs/full-system-console.ps1 (Vision - full hardware acceptance). It
uploads only ignored diagnostic/config files to remote Vision/logs, uses strict
trusted SSH and local password entry, refuses an existing app/audio diagnostic.
First existing C3 checker records5s WAV and cycles all8 NeoPixel states, then
copies WAV privately to ignored laptop logs for playback. User must type PASS
locally only if voice clear and physical colours match. On PASS launches app
for600s: real S3 10.153.76.67,C3 10.153.76.243,UnoQ10.153.76.45,UDP mic,normal
remote photos dir; no laptop camera/microphone in this live path.
Next user actions: authenticate; speak during5s recording/watch colours; listen
and report physical result; after Ready test directions/centre,track person,
shoot and phone gallery http://10.153.76.45:8080. Ctrl+C stops. App/voice logs and
physical-result JSON ignored. Actual full-system acceptance and CPU benchmark
remain pending; no phase declared complete. Optional IR omitted.
Launcher PowerShell parse,bash syntax and YAML validation passed. Latest full
suite126 previously passed; no application change requiring rerun. Existing
HEAD bf89885; no commit/push. Context refreshed before ending this turn.

---

## Full-component test requested; hardware confirmation pending - 2026-10-04

User requested a proper test of all components, using real INMP441/C3 (no
Bluetooth/laptop mic), S3 camera/servos, NeoPixel and Uno Q/gallery. Prepared
sequence: stop microphone diagnostic before binding UDP5005; verify camera
endpoints/motion/capture/ACK/stream recovery, verify C3 PCM clarity and all eight
physical light states, then run existing app on Uno Q with real-board config,
check voice directions/centre, tracking, shoot, photo gallery from phone and
stream recovery; record actual CPU benchmark separately. Optional IR is omitted
in current firmware; do not claim it tested. No firmware implementation changes.

Read-only real S3 /status at10.153.76.67 succeeded:pan/tilt and actual positions
90/90, move_in_progress=false,held_photo=false,RSSI-34,uptime7639s.
Saved logs/full-system-readonly-preflight.json. This is not a motion/capture pass.
Current C3-only remote log reports Listening UDP0.0.0.0:5005 and varying audio
levels; no recognized command evidence found yet. Some zero levels observed;
packet stability and microphone clarity remain unverified. No audio file saved.

SOFTWARE_PLAN.md requires Gate A DONE and Gate B DONE before physical integrated
checks. Latest firmware handoff still marks F2/F3 acceptance pending. Asked user
whether hardware team confirmed camera servo power/capacitors/common ground/free
movement and INMP441/NeoPixel wiring/production firmware plus F2/F3 checks.
Wait for their explicit gate readiness reply before motion/light/capture tests;
do not infer pass from reachability, upload or this request. No full app launched,
no real movements, light commands or photos this turn. Existing Phase5 mock-flow
and CPU benchmark remain pending; user-requested test is recorded without marking
phases complete. Existing HEAD bf89885; no commit/push. Context refreshed.

---

## Current update: C3 microphone selected - 2026-10-04

User explicitly requested INMP441 on ESP32-C3 Super Mini; do not use Bluetooth
headset or laptop microphone. This supersedes earlier boAt preference.
Laptop voice mock has exited with PortAudio channel error; it is not supplying
audio. Firmware handoff confirms production C3 10.153.76.243 sends 16kHz mono
s16le, 512 samples/1024 bytes to Uno Q 10.153.76.45:5005. No firmware edits.
Opening ignored logs/check-c3-mic-console.ps1: password entered only locally,
strict verified host key; uploads diagnostic shell, refuses concurrent app,
then existing tools.demo_voice --mic udp --levels --seconds 180 on Uno Q.
This check recognizes commands only; no camera requests, photos or light commands.
Receiver delivery, speech clarity and acceptance remain pending actual output.
Next: authenticate in C3 console; wait for Listening, say camera track person,
pause, then camera shoot. Review levels/events. Keep camera on laptop mock for
Phase5; do not switch to real S3 or declare firmware gates complete.

Remote source refresh/preflight subsequently succeeded (older failure notes
below are historical): all three models, CSRT/KCF,16 checksums passed.
User's 60s UnoQ-to-laptop read-only stream diagnostic passed:875frames,
60.569s,14.45 received FPS,max chunk gap1.011s,errors[],ok=true,SSH exit0.
PowerShell NativeCommandError on normal SSH connection-close text was cosmetic.
Received FPS is network delivery, not CPU inference benchmark.
Quote-safe deploy/run_phase5.sh and read-only check_mock_network.py added;
latest local full suite126 passed, bash syntax passed. Phase5 full flow,
phone gallery and UnoQ CPU benchmark still pending; no commit/push this update.
Laptop camera mock PID11448 remains active (no automatic expiry); stop owned
mock after acceptance or user stop. Firmware/CAD/editor work preserved.
Context must be refreshed before every commit. Current known HEAD bf89885;
no intended commit yet while acceptance pending.

---

## SSH copy interruption and retry - 2026-10-04T10:13:30+05:30

User reported SCP connection closed by10.153.76.45 after password prompt;
old192.168.29.199 prompt came from our HostKeyAlias. Source refresh did not reach
extraction; no new-runtime success claimed. Cause of disconnect remains unknown.
Strict SSH handshake at currentIP matches previously trusted ED25519 board key;
BatchMode fails only authentication because no passwordless login configured.
Created ignored project logs/phase5-known-hosts from the THREE already trusted
board public keys, mapped to currentIP. Global user SSH settings unchanged.
StrictHostKeyChecking remains yes; no unknown key accepted or verification bypass.
Opened Vision - Phase5 connection retry console: first interactive read-only SSH
must print SSH_LOGIN_OK; then normal SFTP copy, optional SCP -O fallback only if
copy fails after successful SSH login; finally source extraction/check-only/live app.
Prompts now use actual arduino@10.153.76.45. User enters passwords locally, never chat.
Script/result/logs are ignored logs/phase5-{connection-retry,retry-*}; login/copy/
app outcome pending. Script parser passed; no application code changes or new
hardware acceptance. Laptop mocks still use10.153.76.189, headset5.
Next: inspect user reply/result/log. If login fails diagnose SSH before file work;
if app ready resume spoken/phone-gallery test then stop app for UnoQ benchmark.
Phase5 acceptance and benchmark pending. No commit/push; firmware/CAD preserved.

---
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

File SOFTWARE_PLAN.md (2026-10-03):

# Hands-Free Photography Rig — Software Build Plan (for a coding agent)

> Save this file in the repo root. For Claude Code, reference it from `CLAUDE.md`; for Codex, from `AGENTS.md`
> (e.g. "Follow SOFTWARE_PLAN.md phase by phase").

---

## 0. Instructions for the coding agent (read first)

1. **Work strictly phase by phase, in order.** Do not start a phase until the previous phase's acceptance checks pass.
2. **Hardware gates (🛑) are hard stops.** When you reach one:
   - Summarise what is finished and what was tested.
   - Print the gate's checklist for the user, word for word.
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

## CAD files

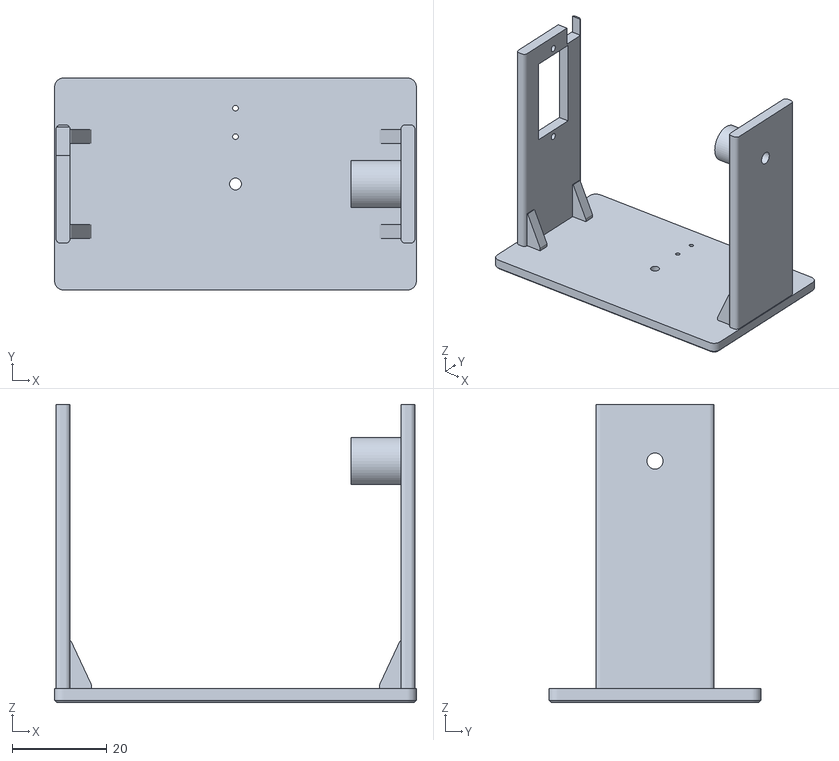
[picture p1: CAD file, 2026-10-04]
enclosure/validation/C2.stl
76.4 x 44.8 x 63.0

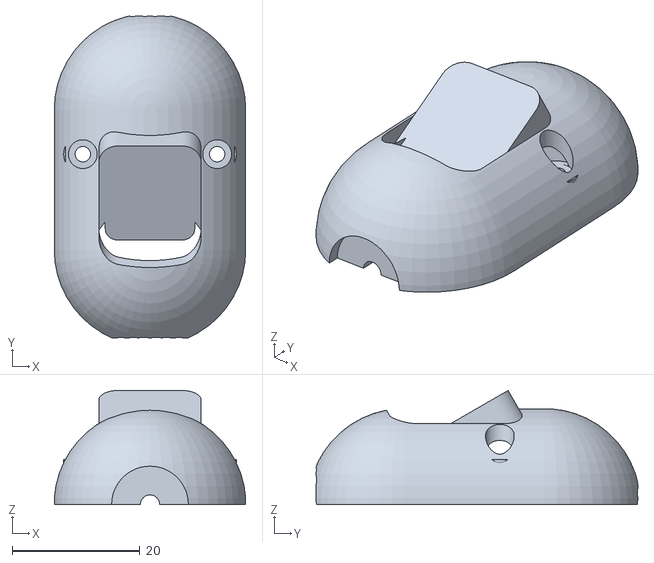
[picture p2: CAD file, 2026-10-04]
enclosure/validation/P7_front.stl
29.9 x 50.3 x 17.8

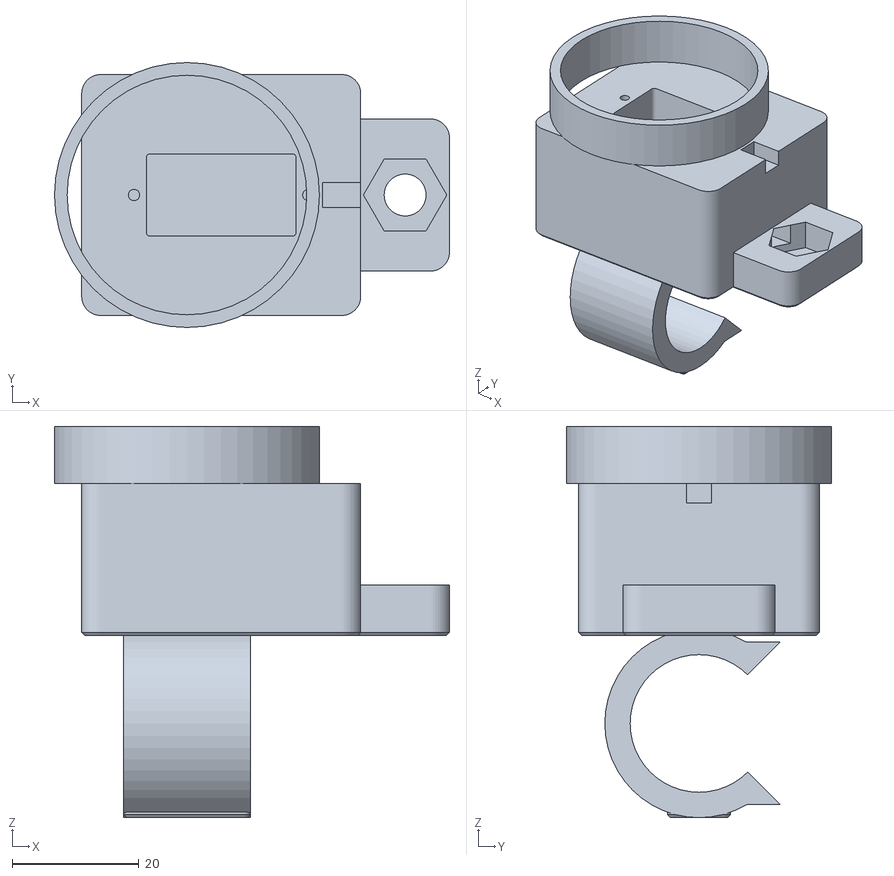
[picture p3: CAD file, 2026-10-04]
enclosure/validation/C1.stl
62.3 x 41.8 x 61.7

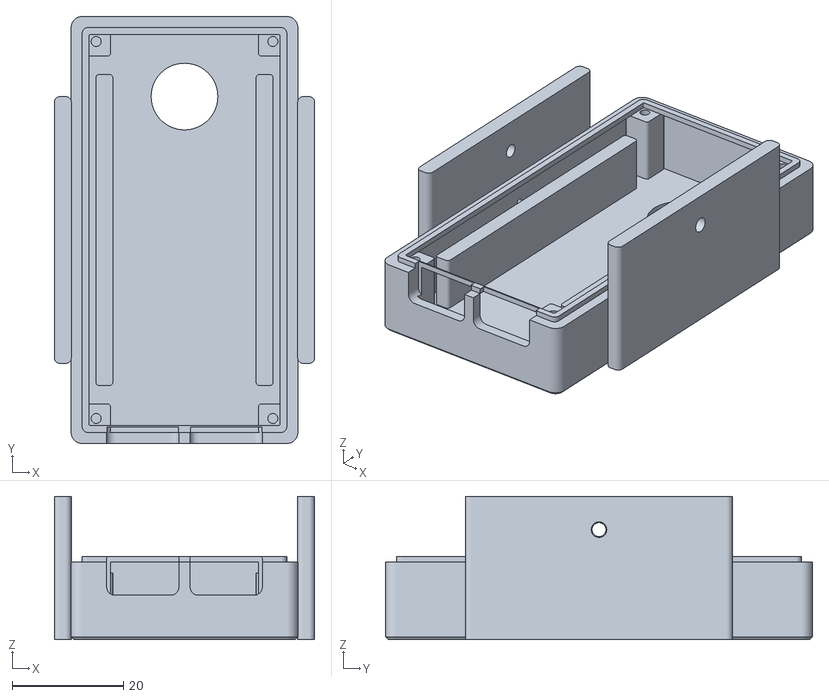
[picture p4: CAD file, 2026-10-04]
enclosure/validation/C3.stl
46.8 x 76.8 x 25.8

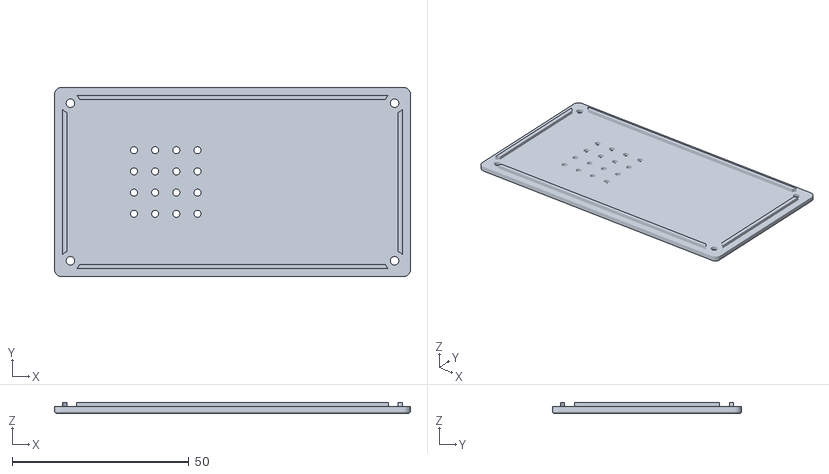
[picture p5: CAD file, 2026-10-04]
enclosure/validation/P6.stl
100.8 x 53.6 x 3.20

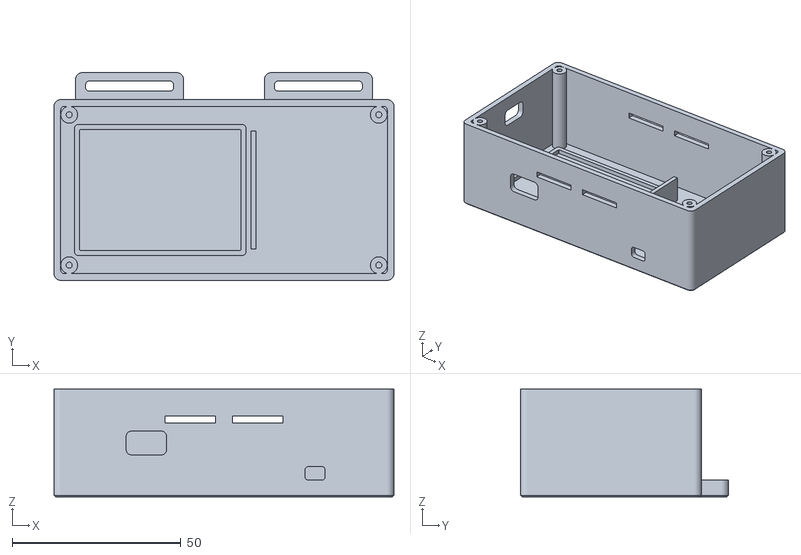
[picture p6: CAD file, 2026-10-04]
enclosure/validation/P5.stl
100.8 x 61.6 x 32.0

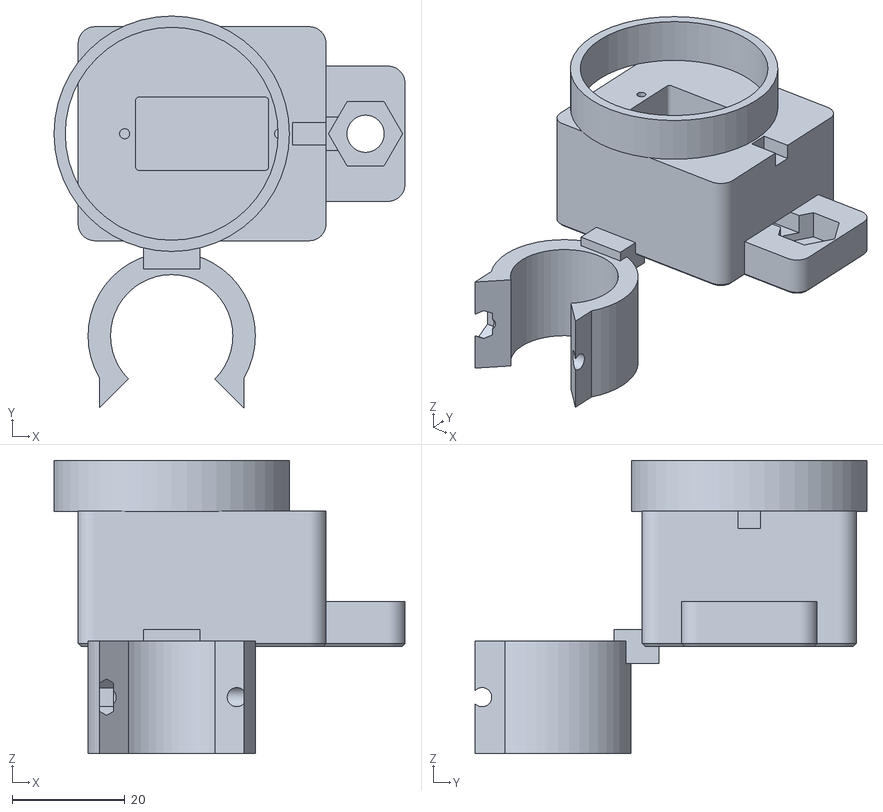
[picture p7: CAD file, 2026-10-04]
enclosure/validation/C1_vertical.stl
62.3 x 69.5 x 52.0

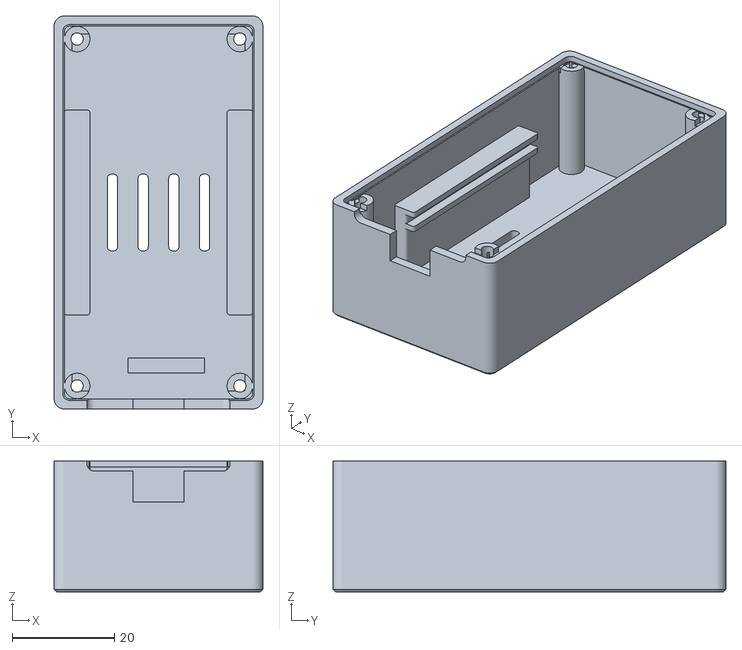
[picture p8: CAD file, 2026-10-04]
enclosure/validation/C4.stl
40.8 x 76.8 x 25.6

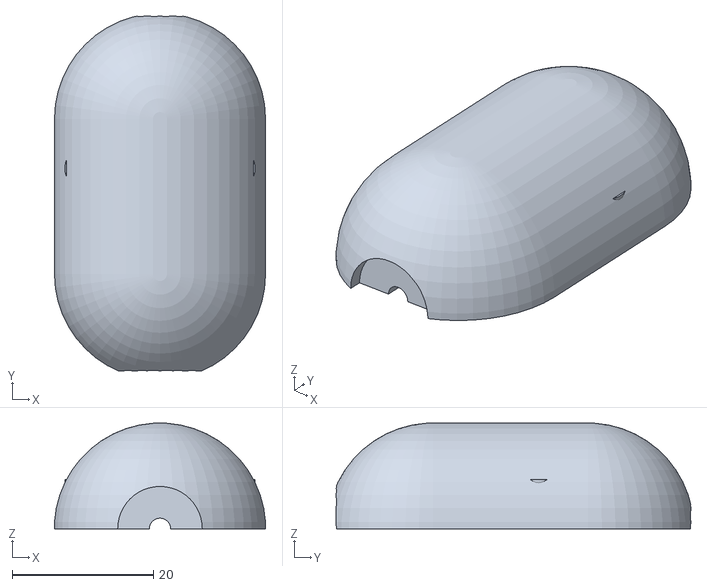
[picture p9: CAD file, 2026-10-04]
enclosure/validation/P7_back.stl
29.9 x 50.3 x 15.0

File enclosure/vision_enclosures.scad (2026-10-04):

/*
  Vision enclosure prototypes -- millimetres, no external libraries.
  Select one part, F6 Render, then Export STL. "layout" is an overview.
  Typical component sizes are NOT measured hardware dimensions.
  Read README.md for deliberate corrections to the reference and print limits.
*/

/* [Output] */
part = "layout"; // [layout,camera_assembly,C1,C1_vertical,C2,C3,C4,P5,P6,P7_front,P7_back]
quality = 48;
preview_tilt = 0; // [-30:45]

/* [Measured components - replace these typical values] */
servo_l = 22.8;
servo_w = 12.2;
servo_below_tabs = 20;
servo_hole_pitch = 27.5;
servo_shaft_from_end = 6;
tilt_servo_projection = 8.5; // tab seating face to output face; measure!
tilt_horn_thickness = 2;
horn_length = 20; // hub centre to far tip, conservative interpretation
horn_width = 5;
horn_hub_d = 7;
horn_tie_positions = [10,16]; // replace with measured hole positions
post_d = 22;
pcb_w = 28;
pcb_h = 64;
pcb_t = 1.6;
lens_x = 0;
lens_from_pcb_top = 8; // PLACEHOLDER: measure!
usb_x = [-7.5,7.5]; // PLACEHOLDERS: centres from PCB centre
usb_depth = 12; // centre from outer front face; measure connector stack
perf_w = 30;
perf_h = 40;
perf_t = 1.6;
header_space = 10;
capacitor_space = 12;
breadboard_l = 47;
breadboard_w = 35;
breadboard_h = 8.5;
voice_usb_x = -23; // PLACEHOLDER in box coordinates
voice_usb_z = 16; // PLACEHOLDER above print bed
charger_usb_x = 27; // PLACEHOLDER
mic_d = 14;
mic_t = 2; // PLACEHOLDER: module excluding pins
mic_sound_x = 0; // PLACEHOLDER: offset of actual sound port
mic_sound_z = 0;
arm_d = 7;

/* [Fit and optional features] */
clearance = 0.4; // per side
wall = 2;
bottom_chamfer = 0.5;
lip_clearance = 0.3; // per side
clamp_interference = 0.3; // DIAMETRAL, verify with a test coupon
horn_pocket_depth = 1.5;
camera_hood = 0; // 0 for flat front-down bed contact; 1.5 adds outward hood
engrave_labels = true;
tilt_min = -30;
tilt_max = 45;

/* [Hidden] */
$fn = quality;
eps = 0.02;
m2_pilot = 1.8;
m2_clear = 2.4;
m3_pilot = 2.8;
m3_clear = 3.4;
servo_offset = servo_l/2-servo_shaft_from_end;
pan_bearing_id = max(30,2*sqrt(pow(servo_offset+servo_l/2+clearance,2)+pow(servo_w/2+clearance,2))+1);
pan_bearing_height = max(1,tilt_servo_projection+tilt_horn_thickness-horn_pocket_depth);
cam_w = max(pcb_w+2*clearance+8,perf_w+2*clearance+6)+2*wall;
cam_h = pcb_h+2*clearance+8+2*wall;
cam_front = wall+10+pcb_t+clearance;
cam_back = header_space+perf_t+capacitor_space+wall;
cam_depth = cam_front+cam_back;
tilt_depth = cam_depth/2;
boss_projection = 3;
case_across_bosses = cam_w+2*boss_projection;
tilt_side_gap = tilt_servo_projection+tilt_horn_thickness+1;
yoke_gap = case_across_bosses+2*tilt_side_gap;
yoke_t = 3;
yoke_w = max(50,yoke_gap+2*yoke_t+0.6);
yoke_d = max(30,2*(horn_length+clearance+2));
tilt_axis = max(48,sqrt(pow(cam_h/2,2)+pow(cam_depth/2,2))+3);
arm_h = max(60,tilt_axis+11);
cam_screws_x = cam_w/2-wall-2.5;
cam_screws_y = cam_h/2-wall-2.5;
voice_iw = breadboard_l+2*clearance+49;
voice_id = max(breadboard_w+2*clearance+8,25+17+4*clearance+6);
voice_w = voice_iw+2*wall;
voice_d = voice_id+2*wall;
voice_h = max(30,breadboard_h+20)+wall;
bb_x = -voice_iw/2+6+breadboard_l/2;
voice_sx = voice_w/2-wall-2.5;
voice_sy = voice_d/2-wall-2.5;
pod_d = 30;
pod_l = 52;
pod_r = pod_d/2;
pod_screw_x = 10.5;
pod_screw_y = 4;

assert(wall>=1.2 && clearance>=0 && lip_clearance>0);
assert(quality>=16);
assert(servo_shaft_from_end>0 && servo_shaft_from_end<servo_l);
assert(cam_back-wall>=header_space+perf_t+capacitor_space);
assert(abs(lens_x)+6<cam_w/2-wall);
assert(lens_from_pcb_top>6 && lens_from_pcb_top<pcb_h-6);
assert(arm_d>1 && arm_d<12);
assert(mic_d+0.6<22 && mic_t>0 && mic_t<=4);
assert(preview_tilt>=tilt_min && preview_tilt<=tilt_max);
assert(part=="layout" || part=="camera_assembly" || part=="C1" || part=="C1_vertical" || part=="C2" ||
       part=="C3" || part=="C4" || part=="P5" || part=="P6" ||
       part=="P7_front" || part=="P7_back","Unknown part selector");

// Rounded footprints have a true planar base. Offset maintains overall sizes.
module rounded2(w,d,r=2) {
    offset(r=r) square([w-2*r,d-2*r],center=true);
}
module rounded_box(w,d,h,r=2,ch=bottom_chamfer) {
    if(ch>0) {
        hull() {
            linear_extrude(eps) rounded2(w-2*ch,d-2*ch,max(r-ch,0.1));
            translate([0,0,ch]) linear_extrude(eps) rounded2(w,d,r);
        }
        translate([0,0,ch]) linear_extrude(h-ch) rounded2(w,d,r);
    } else linear_extrude(h) rounded2(w,d,r);
}
module drill_x(d,h) { rotate([0,90,0]) cylinder(d=d,h=h,center=true); }
module drill_y(d,h) { rotate([90,0,0]) cylinder(d=d,h=h,center=true); }
module hex_hole(af,h) { cylinder(d=af/cos(30),h=h,$fn=6); }
module screw_grid(x,y) { for(a=[-1,1],b=[-1,1]) translate([a*x,b*y,0]) children(); }
module frame(w,d,h,t=1.2,r=2) {
    difference() {
        rounded_box(w,d,h,r,0);
        translate([0,0,-eps]) rounded_box(w-2*t,d-2*t,h+2*eps,max(0.3,r-t),0);
    }
}
module countersink(hole=2.4,head=4.5,depth=1.1) {
    // Exterior face at z=0; countersink narrows inward into +Z.
    translate([0,0,-eps]) cylinder(d1=head,d2=hole,h=depth+eps);
}
module horn2() {
    circle(d=horn_hub_d+2*clearance);
    hull() {
        circle(d=horn_width+2*clearance);
        translate([horn_length-horn_width/2,0]) circle(d=horn_width+2*clearance);
    }
}
module horn_cut(depth) {
    linear_extrude(depth) horn2();
}

// C1: shaft centred on X=Y=0. Separate horizontal and vertical tube variants.
module collar() {
    ir=(post_d-clamp_interference)/2;
    rr=ir+4;
    difference() {
        union() {
            cylinder(r=rr,h=20);
            for(s=[-1,1]) translate([s*(ir*0.72+2),ir*0.88,10])
                cube([6,10,20],center=true);
        }
        translate([0,0,-eps]) cylinder(r=ir,h=20+2*eps);
        translate([0,0,-eps]) linear_extrude(20+2*eps)
            polygon([[0,0],[-rr*2,rr*2],[rr*2,rr*2]]);
        translate([0,ir*0.88+2,10]) drill_x(m3_clear,2*rr+20);
        translate([ir*0.72+2+3-2.5,ir*0.88+2,10])
            rotate([0,90,0]) hex_hole(5.6,3);
    }
}
module C1(vertical=false) {
    rr=(post_d-clamp_interference)/2+4;
    base_z=vertical?19:2*rr-1;
    cup_h=servo_below_tabs+4;
    cup_w=max(44,servo_l+2*clearance+14);
    cup_d=38;
    difference() {
        union() {
            if(vertical) {
                translate([0,-rr-cup_d/2-2,0]) rotate([0,0,180]) collar();
                translate([0,-cup_d/2-1,19]) cube([10,8,6],center=true);
            }
            else translate([-10,0,rr]) rotate([0,90,0]) collar();
            if(!vertical) translate([0,0,0]) rounded_box(20,10,3,1,0.5);
            translate([servo_offset,0,base_z]) rounded_box(cup_w,cup_d,cup_h,3);
            translate([0,0,base_z+cup_h-eps]) difference() {
                cylinder(d=pan_bearing_id+4,h=pan_bearing_height+eps);
                translate([0,0,-eps]) cylinder(d=pan_bearing_id,h=pan_bearing_height+3*eps);
            }
            // Tripod flange extends beside the tube, under an accessible top.
            translate([servo_offset+cup_w/2+5,0,base_z]) rounded_box(18,24,8,3);
        }
        translate([servo_offset,0,base_z+2])
            rounded_box(servo_l+2*clearance,servo_w+2*clearance,cup_h+3,0.6,0);
        for(s=[-1,1]) translate([servo_offset+s*servo_hole_pitch/2,0,base_z+cup_h-8])
            cylinder(d=m2_pilot,h=10);
        translate([servo_offset+cup_w/2,0,base_z+cup_h-1.5]) cube([12,4,3.1],center=true);
        translate([servo_offset+cup_w/2,0,base_z+6]) cube([12,6,4],center=true);
        translate([servo_offset+cup_w/2+7,0,base_z-eps]) {
            cylinder(d=6.6,h=9);
            translate([0,0,2.4]) hex_hole(11.1+0.3,5.7);
        }
    }
}
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

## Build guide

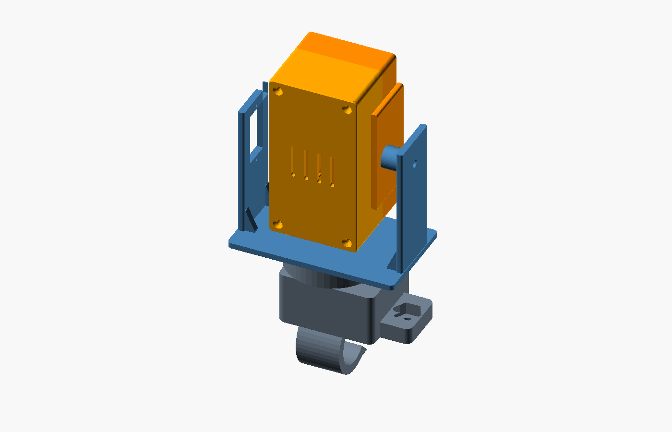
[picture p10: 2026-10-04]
enclosure/validation/camera_assembly.png

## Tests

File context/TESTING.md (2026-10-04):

# Verification and runnable commands

## Session publication and resume point - 2026-10-04

User requested context refresh, commit and push of all pending project work.
Existing HEAD: d64f754f219d4b983a32bd87f740309fc2920e41.
Intended message: feat: add switchable BLE voice transport and network diagnostics.
Publication includes the previously implemented runtime freshness fix, network
migration/diagnostic changes, optional BLE transport and switching tools, tests,
and durable context. No additional firmware edits or hardware run in this
publication turn. Ignored credentials, models, logs and private media excluded.

Resume by reading context/README.md, HANDOFF.md, STATUS.md, BLE_TRANSPORT.md and
FIRMWARE_NETWORK_ISSUE.md. Full app is STOPPED. Current C3 mode BLE; verified
address44:B1:76:17:F5:7E. Uno Q USB ADB serial662499217, runtime/home/arduino/Vision.
Uno Q routerIP192.168.1.99; S3 last verified192.168.1.122; C3 Wi-FiIPunknown.
Root config.yaml retains prior hotspot addresses172.20.10.2/4/5; this is a stale
configuration snapshot, not current router addressing. Do not run it unchanged.

142 tests passed in9.73s after the final buffer change; diff whitespace check
passed. Strict final BLE40.019s:16004.26samples/s, no missing samples or padding,
but maxgap101ms fails <100ms requirement. NeoPixel colors not watched/unverified.
S3 status/stream timeout;0frames. No complete voice/camera integration acceptance.
Keep UDP selectable; switching is by reflash, not a live toggle. Shared canonical
UDP contract unchanged. Session A must not edit firmware under current rules;
Session B owns S3 connectivity and BLE sender follow-up. Do not advance phases.
Next action: diagnose S3 connectivity and remaining BLE timing in Session B,
then repeat strict BLE probe/physical light verification before full integration.
See the following entry and BLE_TRANSPORT.md for exact commands and measurements.

---

## Switchable BLE trial implemented; acceptance pending - 2026-10-04

User requested BLE while retaining Wi-Fi/UDP selection. Earlier in this work,
a narrow C3 BLE prototype was implemented/flashed under that request; current
Session A ownership instructions prohibit further firmware edits. Session B owns
firmware follow-up. SOFTWARE_PLAN section 2 is unchanged; BLE is experimental,
not an adopted replacement contract. See context/BLE_TRANSPORT.md for framing,
files, mode-switch commands and the measured results.

C3 currently runs BLE, address 44:B1:76:17:F5:7E. Uno Q receives INMP441 audio
and sends NeoPixel states over one connection; no headset/laptop microphone.
Both modes compile and BLE -> UDP -> BLE reflashing was verified, same partition.
UDP is still the default build/app mode; switching requires reflash in this trial.
C3 Wi-Fi authentication remains unresolved; its router DHCP address is unknown.
Uno Q 192.168.1.99, last verified S3 192.168.1.122. Existing full-system config
still contains old hotspot addresses: do not launch it unchanged on TinkerSpace.

Latest full local suite: 142 passed in 9.73s; focused BLE suite 6 passed in 0.30s.
Final serial-closed BLE probe: 40.019s, 640480 samples, 16004.26 samples/s,
zero missing/invalid/out-of-order samples, buffer drops or playout padding.
Maximum notification gap 0.101s narrowly exceeds the unchanged strict <0.100s
gate: report ok=false, transport acceptance PENDING. Prior probe had 272 padded
samples; startup cushion increased from 3 to 4 chunks (128ms) and eliminated
padding in this final sample. Earlier 40s loss-free result passed the older gate
before playout padding was measured; do not treat it as final acceptance.
Concurrent S3 read-only probe: 0 frames; status/stream timeout, ok=false.
Light writes requested previously; user says they did not watch NeoPixel, so
physical colors remain UNVERIFIED. No Vosk/full-command or standalone acceptance
in this trial. No private media saved. Full Vision app STOPPED; probes ended.

Next: Session B investigate S3 connectivity and remaining BLE timing; then
repeat strict BLE audio check, visually verify light colors, and run real voice/
camera integration using verified current config. Do not mark phases/gates done.
Existing HEAD d64f754f219d4b983a32bd87f740309fc2920e41. User subsequently authorized publication; see the newest publication entry
for the intended message and existing HEAD. Refresh context before any commit.

---

## Bluetooth alternative discussed - 2026-10-04

User interrupted further driver-report/toolchain inspection to ask about using
Bluetooth. No spare C3 available, user-reported. Previous temporary diagnostics
restored to production with verified uploads; Uno Q on TinkerSpace and app stopped.
No SDK install/downgrade or BLE implementation performed. Bluetooth is currently
an architectural option only: C3 INMP441 PCM needs32kB/s raw (16kHz16bitmono),
so BLE audio/light transport needs a measured throughput/reliability prototype;
camera remains Wi-Fi. C3 Wi-Fi/BLE share antenna, so BLE success cannot be assumed
if RF/hardware is implicated. Any production BLE transport changes require user
approval of shared SOFTWARE_PLAN section2 plus coordinated Session A/B work.
Next: respond to Bluetooth tradeoff, then obtain explicit direction before new
transport implementation or resume Wi-Fi driver/PHY diagnosis. No phase/gate
completion, commit/push, or automatic app restart. Existing HEADd64f754.

---

## Router isolation performed; no successful fix yet - 2026-10-04

User requested find/fix. Read FIRMWARE_NETWORK_ISSUE.md for exact tests/results.
C3 fails in Wi-Fi-only sketches without microphone/NeoPixel software activity;
sees router-62/-64dBm but cannot authenticate, even targeted BSSID/channel and
lower transmit power. Its temporary access point reports started but is absent
from fresh Uno Q scans. This narrows investigation to radio/driver/calibration,
RF/power or AP behavior; no board defect or root cause conclusively established.
S3 b/g and Uno Q powersaveOFF comparisons failed; both experiments reverted.
User says hotspots off and alternate power/cable ready; post-report probes still
fail. Do not claim independently verified physical supply changes.
Temporary C3 diagnostics restored to production1000105/37976; S3 production
986425/56664 restored. Uploads0/hashesverified. Uno Q router profile restored,
actualpowersaveON/default0, temporary NM profile/helper removed. All bounded
readers/probes ended. Vision STOPPED; old runtime config must not launch on
router until unknown C3 DHCP address is verified and all configs updated.
User spare-C3 availability question pending. Next: identified spare-board radio
comparison if available, otherwise Session B driver/PHY and hardware/RF/AP logs.
No erase/NVS reset, guessed pins, future-phase work, commit or push. Existing
HEADd64f754f219d4b983a32bd87f740309fc2920e41. Prior136 software tests unchanged;
full stability/commands/gallery/benchmark and F2/F3 acceptance still pending.
Update context before every commit and when ending; preserve Session B ownership.

---

## TinkerSpace migration partially applied - 2026-10-04

User selected regular Wi-Fi TinkerSpace instead of the phone hotspot and
confirmed local connection prompt success. Existing network-only firmware
compile/upload and Wi-Fi-fix authorization persists. No broader firmware scope.
USB ADB remains available; runtime STOPPED, no automatic restart/commit/push.
Existing HEAD d64f754f219d4b983a32bd87f740309fc2920e41.

Uno Q initially still on hotspot despite reported success; activated saved
TinkerSpace UUID aeab9e46-0448-450f-bd4e-fcd105990a37. Verified WPA2 2.4GHz
2462MHz association and DHCP192.168.1.99/24. S3 joined192.168.1.122,
MAC28:84:85:a1:85:ec, RSSI-52. C3 router DHCP IP UNKNOWN: do not guess.
User says both boards are close to router with clear antennas.

Both ignored SSID/password settings synchronized from active Uno Q profile,
without displaying password; unescaped extraction equality verified for both.
C3 destination IPAddress192.168.1.99; DHCP retained. Initial script expected a
macro instead of IPAddress and aborted C3 update; corrected and recompiled
before upload. Verified COM19 S3 / COM18 C3 chip and MAC identities. S3 compile
986425/56664 bytes and upload0/hashverified. C3 final1000105/37976 and upload0/
hashverified. Network-only C3 changes: removed prior8.5dBm transmit cap to SDK
default; disabled automatic reconnect, retained45s manual retries to avoid rapid
authentication loop. Neither change established successful router association.
No pins, capture, audio conversion or shared contract changes.

C3 initial/default-power logs repeatedly disconnect reasons2/201/36. Final50s
bounded-reconnect sample shows boot and three reason2 events, NO connectedIP.
No full audio probe run because peer address unknown. S3 initial router probe
HTTPstatus/stream timeout, 0frames; repeated probe0frames/62bytes, HTTPstatus
connecttimeout and streamreadtimeout. Captured report logs/router-camera-delivery.json
ok=false. Uno Q-to-S3 firstping753-904ms; later32-157ms, router53-151ms:
variable latency, not proof of a single AP or power cause. S3 connection succeeds
but usable HTTP stream not verified. All bounded serial readers/probes ended.

Root config.yaml and real runtime config still hold prior hotspot addresses:
DO NOT launch them on this network. Only ignored camera diagnostic config was
prepared using verified router IPs; no inferred C3 address. Complete all address
updates once C3 connects, then copy verified runtime config to Uno Q.
Next: resolve C3 WPA2 association (coordinate Session B/router administrator for
isolated association diagnostics), verify S3 HTTP recovery, then repeat concurrent
metadata delivery with C3 serial closed. Only after usable board connectivity
restart unrestricted user-command run. No phase/gate acceptance or stability
pass; prior136 software tests unchanged, not rerun for network-only work.
Secrets/helpers/builds/reports remain ignored; no private media saved to context.
Update handoff before every commit and when ending, preserving both sessions.

---

## Latest transport results; runtime stopped - 2026-10-04

Supersedes earlier pending-build and active-run records below. User reported
freshness interruptions again on the new hotspot. Vision remains STOPPED:
ADB pgrep app.main found no process. No automatic restart, commit or push.
Existing HEAD d64f754f219d4b983a32bd87f740309fc2920e41; no commit requested.

Under the user's explicit Session A Wi-Fi diagnostic/fix exception, compiled
and flashed both boards successfully (exit 0, flash hashes verified). C3 build
1000357 program / 37976 global bytes includes bounded ENOMEM/EAGAIN send retries
and preserved socket on transient failure. S3 build 986425 / 56664 includes
TCP_NODELAY on accepted HTTP sockets and bounded frame/send timing diagnostics.
Pins, camera acquisition/quality, microphone conversion and shared contract
unchanged. Secrets stay ignored. No media or credentials recorded here.

Final concurrent metadata-only sample with C3 serial CLOSED:
- C3: 842 valid packets / 30.260s = 27.83/s (expected 31.25), max gap 0.867s,
  20 gaps >100ms; zero malformed/other-peer packets and kernel UDP errors.
- S3: 74 frames / 25.427s = 2.91 FPS, maximum chunk gap 1.166s;
  status response 0.272s, RSSI -27. Report ok=true means finite HTTP delivery
  succeeded, NOT tracking stability acceptance.
- S3 timing while stream open: max camera frame wait 1ms, max network send wait
  1009ms then 1626ms. Closing sample showed 2524ms / result 0xb006; client was
  deliberately finite, so do not attribute that closing failure independently.
This separates camera acquisition from observed transport stalls. C3 previously
reported send-stage errno12/ENOMEM. Retry samples improved average delivery,
but remaining stalls prevent declaring the issue fixed or F2/F3 acceptance.

Uno Q powersave-OFF comparison did not improve delivery; actual radio restored
ON and saved profile to original default0. IPs: Uno Q172.20.10.2, C3172.20.10.4,
S3172.20.10.5. Laptop on Jasil; USB ADB forwards localhost:8080 to Uno Q gallery.
All bounded probes/readers ended. Prior software suite136 passed remains the
last result; not rerun for these network-only changes. Full19-command/features,
physical lights, smooth tracking, photo flow, phone gallery, benchmark, power
under load and standalone stability remain pending; no phase advanced.

Evidence: ignored logs/new-network-camera-final-timing.json,
logs/new-network-c3-final-timing.json, logs/new-network-s3-final-timing.log,
and final firmware compile/upload logs. Next: controlled comparison on a
non-phone 2.4GHz access point, with board destinations verified and the same
metadata probes; distinguish AP/transport behavior from board RF/power causes.
Do not silently change SSIDs or flash broader firmware. Restart freeform Vision
only when requested, with no timer and user-selected commands. Update context
before every commit; coordinate any further firmware work with Session B.

---

## New-network retry ended; deeper transport diagnosis - 2026-10-04

User reported same freshness interruptions. Verified PID14195 absent, UDP5005
listener absent, freeform result exit0. Runtime is STOPPED; no automatic restart.
Earlier active-run handoff is historical. User authorization for Session A Wi-Fi
diagnostics/fixes continues for this repair, with pins/capture/PCM contract fixed.

Uno Q NetworkManager permissions allow profile changes without sudo. Live
reapply of Wi-Fi powersave was unsupported; temporary saved-profile disable +
reconnect worked. Power-OFF concurrent sample: C3525/40.033s=13.11/s,maxgap3.126s;
camera36frames/21.366s=1.68FPS,maxchunkgap1.854s,status1.360s,readtimeout. No
improvement. Restoring profile default did NOT restore actual radio ON; corrected
by enabling3/reconnecting, then resetting saved profile to original default0.
Verified iw Power save ON and original profile default. No persistent power fix.

Precise C3 diagnostics exposed last_errno12/ENOMEM at stage send while receiver
active and no camera stream. Before retry:596/40.240s=14.81/s,maxgap1.092s,
0malformed/kernel receive errors; sender failures grew at UDPsend. Implemented
bounded transient ENOMEM/EAGAIN retry: failed sends only,2ms waits within16ms,
no duplicate after success,no offline replay; preserve existing socket for these
transient errors. Other errors still reset socket. Raw1024byte/16kHz/512sample
contract and microphone conversion untouched; producer log remains zero-wait.
Compile1000357 program/37976globals; upload0/hashesverified. Post retry sample
1120/40.495s=27.66/s,maxgap1.158s,0malformed/kernel errors. Send errors/retries
still occur. Improvement in this sample,NOT full audio stability or F3 pass.
Reader open during both errno/retry samples; serial-closed acceptance still needed.

Now compiling S3 network TCP_NODELAY accepted-socket experiment plus bounded
10s frame-wait/send-wait maxima to separate camera wait from transport delay.
No frame size,quality,sensor,servo,pin,endpoint or shared contract change.
This S3 build is NOT YET deployed/verified. Next: complete compile/upload and
40s metadata-only concurrent delivery + S3 timing capture; retain changes only
if measured useful. Latest verified board IPs UnoQ172.20.10.2,C3.4,S3.5. Laptop
previous hotspot,USB live URLlocalhost:8080/live; runtime remains stopped.
No commit/push,serviceactivation or full hardware acceptance. Update context
before every commit and when ending; preserve Session B records.

---

## New-network real-component run active; lag persists - 2026-10-04

User requested migration, all IP updates and another unrestricted real run.
User explicitly authorized two Session A exceptions: network-only secret/settings
build/upload, then Wi-Fi diagnostics/connection fixes. This does not authorize
unrelated firmware features/pins/contract edits or future phases. Corrected both
ignored SSIDs to verified laptop network, preserved user-entered passwords,
set C3 UNOQ_IP172.20.10.2, retained DHCP. Secrets remain ignored, not printed.
Verified chip/MAC/ports before upload. C3 final compile999979/37976 bytes,
S3 final compile986161/56664; final uploads exit0 with verified flash hashes.

S3 initially could not join. Added bounded disconnect reason/count reporting
(13 source lines; callback only updates counters, main reports at most2s).
Temporary S3 TX8.5dBm cap did NOT solve association; removed and flashed final
build with original transmit power. No other sketch behavior/pins/capture/audio
conversion/lights changed. New reporting revealed reason5 (ASSOC_TOOMANY,
access point unable to handle associated clients). Controlled test disconnected
ONLY Uno Q Wi-Fi while USB remained: S3 immediately joined172.20.10.5, whereas
Uno Q then failed rejoin. User says only laptop/UnoQ/C3 were connected. This
supports hotspot capacity in this observed setup, not a universal iPhone limit.
User moved laptop back to Jasil after Windows location policy blocked CLI switch.
Uno Q then rejoined successfully; all three board MACs reachable on new network.

Current verified board IPs: Uno Q172.20.10.2/28, C3172.20.10.4, S3172.20.10.5;
gateway172.20.10.1. Root config.yaml AND remote root/full-system config updated.
Laptop is on previous network and does not occupy new-hotspot slot. USBADB
662499217 forward tcp8080 -> UnoQ tcp8080 provides http://localhost:8080/live.
Application computation still entirely Uno Q; USB/laptop only console/live view.
Direct gallery on new network http://172.20.10.2:8080 (phone access unconfirmed).
ADB forwarding must be recreated after disconnect/device restart; no auto-start.

New-network delivery checks, serial monitors CLOSED, no capture/move/light:
Initial C3-only40.132s:388 valid packets,9.67/s,maxgap9.517s; not repaired.
After three boards could join, concurrent40s C3 + camera: C3993/40.010s,
24.82/s vs31.25expected,maxgap.639s,0malformed/kernel receive errors. Camera
20frames over13.065s,1.53receivedFPS,maxchunkgap1.197s,status1.106s; requested40s
ended early with2s readtimeout. Diagnostic okfalse. Changing network has NOT
eliminated delivery issues; these are network measurements, not CPU benchmark.
No claim of exact loss, smooth motion, WAV clarity, colours or full acceptance.

Requested app launched successfully, actual PID14195, UDP5005 owned by app,
--mic udp --seconds0 and real full-system config. USB /live and /live/frame.jpg
HTTP200; browser opened localhost live URL. Startup/calibration and camera sync
completed; repeated freshness warnings still observed. Accepted camera up at
08:04:15(board log clock); physical action not yet confirmed. No guided commands,
voice injection or automatic tracking; user chooses commands. Run continues
until user stops, no expiry or service activation. All diagnostics/readers ended.

Ignored logs retain final builds/uploads, serial association evidence, new-
network-camera-delivery.json and new-network-c3-delivery.json. Configuration
validation passed locally and on Uno Q. Prior136 software-test result unchanged;
not rerun for this firmware/network-only work. No commit/push requested. Existing
HEADd64f754; firmware/STATUS/context records updated under explicit exception.
Pending: user live feedback, residual stream/audio diagnosis, power under load,
full19-command/features/phone gallery acceptance, CPUbenchmark and standalone
acceptance. Next: observe freeform results or stop exact owned app on request;
never label network migration a stability pass. Refresh context before any commit.

---

## New-network uploads completed; S3 connection blocker - 2026-10-04

User explicitly authorized this Session A to compile/upload EXISTING sketches
and update network addresses only, overriding the normal Session B boundary
for this narrow task. No sketch implementation changed. Verified chips/MACs
before writing: C3 COM18 ESP32-C3 AZrev1.1/44:b1:76:17:f5:7c; S3 COM19
ESP32-S3 rev0.2/28:84:85:a1:85:ec. User-edited secrets initially did not match
laptop SSID exactly. Corrected SSID in both ignored headers to the observed
network, preserved user passwords, set C3 UNOQ_IP172.20.10.2. Both passwords
compared equal without printing values. DHCP1 retained; no guessed static IPs.

Both final builds succeeded: C3 999979 program/37976 globals; S3 984997/56656.
Both final uploads exited0, flash hashes verified and boards reset. Pins,
servo/camera/microphone conversion/light behavior/shared contract unchanged.
Source diff confirms neither sketch edited. Secret headers still Git-ignored.
One earlier successful upload had the nonmatching SSID; final uploads replace it.

Uno Q now on new iPhone network, DHCP172.20.10.2/28, gateway172.20.10.1;
laptop172.20.10.3. Uno Q fell back to old network once during uploads; manually
reactivated verified new profile and rechecked it remains new. Do not assume
future reconnections keep this DHCP destination; verify before later uploads.
C3 joined172.20.10.4; MAC confirmed by neighbour and serial boot. LightUDP5006
ready, audio destination172.20.10.2:5005. Ping averaged24ms in3 probes, but
sustained serial-CLOSED receiver40.132s got only388 packets (9.67/s), max gap
9.517s, zero malformed/other-peer/kernel receive errors. New network has NOT
resolved audio delivery. Source sender/network causal attribution still pending.

S3 has NOT joined; no confirmed new IP. Serial repeated Wi-Fi state changes
and E wifi:Set status to INIT after upload and after one authorized restart.
Camera/PSRAM/OV3660 initialization succeeds; latest boot reset_reason1 is
explicit tool reset, not a new inferred spontaneous brownout. No fresh BOD
message captured. User says iPhone Maximize Compatibility already enabled;
scan reports hotspot2437MHz. Password equality alone does not identify fault.
No extra connection behavior change authorized under network-only exception.
Asynchronous question asks user to authorize Wi-Fi diagnostics/connection fixes
here or hand remaining firmware issue back to Session B. Await decision.

Root config.yaml and ignored full-system config have UnoQ172.20.10.2 and
C3172.20.10.4. S3 field still OLD10.153.76.67; NOT ready for full runtime.
Launch console URL updated172.20.10.2:8080/live; app remains STOPPED, no full
new-network run or camera comparison claimed. Local config validation passed;
prior136 software tests not rerun for configuration/build-only changes.
Ignored logs hold build/upload/serial and new-network-c3-delivery.json metadata;
no speech WAV/media or credentials included in handoff. Serial readers closed.

No commit/push or service activation. Existing HEADd64f754. All physical
acceptance/CPUbenchmark pending. Exact next action: resolve Wi-Fi diagnostic
ownership, diagnose S3 association and C3 gaps, verify S3 IP by MAC/status,
finish runtime config/deployment, then run requested unrestricted live test.
Respect user no guided voice sequence and no time limit. Update context before
any future commit; preserve both sessions' records.

---
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

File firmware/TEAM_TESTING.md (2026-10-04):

# F1 bench firmware: hardware team handoff

Prototype scope update (2026-10-04): user deferred optional IR to TODO.md.
IR physical testing is skipped for this version. Servo, NeoPixel and microphone
checks are required. The exact original gate below is preserved for reference;
its optional IR item is omitted under this user direction.

These are actual standalone firmware sketches. Test each part before camera/
voice integration. All Serial output uses 115200 baud. Boot logs show numeric
ESP reset reason; Wi-Fi is intentionally disabled and there is no bench IP.
No camera_head/voice_unit runtime firmware is implemented yet.

## Toolchain and compilation

Install Arduino CLI on PATH (or pass -Cli /path/to/arduino-cli.exe to the script).
From the repository root:

```powershell
arduino-cli core update-index --additional-urls https://espressif.github.io/arduino-esp32/package_esp32_index.json
arduino-cli core install esp32:esp32@3.3.11 --additional-urls https://espressif.github.io/arduino-esp32/package_esp32_index.json
arduino-cli lib install ESP32Servo@3.2.1 "Adafruit NeoPixel@1.15.5"
./firmware/tools/verify_bench.ps1 -IncludeServoStress
arduino-cli board list
```

S3: ESP32S3 Dev Module, 16MB flash, OPI PSRAM for N16R8. Default S3 Serial
is UART: use the board's USB-to-UART connector. If using its native USB/OTG
connector, compile with `-S3Fqbn 'esp32:esp32:esp32s3:PSRAM=opi,FlashSize=16M,CDCOnBoot=cdc'`.
C3 SuperMini: ESP32C3 Dev Module with USB CDC On Boot enabled.
The script prefers the local portable CLI/libraries when present, otherwise
uses your installed CLI/libraries. Toolchains/builds are not shipped in Git.

## Upload and Serial

Identify the correct board and replace COM_S3 / COM_C3 with its actual port.
Run these manually only when that board is plugged in and the hardware lead
authorizes flashing. Nothing here automatically uploads.

```powershell
# S3 UART connector, normal one-servo-at-a-time sweep:
arduino-cli upload --fqbn esp32:esp32:esp32s3:PSRAM=opi,FlashSize=16M --port COM_S3 --input-dir ./firmware/.build/servo_sweep ./firmware/bench/servo_sweep
arduino-cli monitor --port COM_S3 --config baudrate=115200

# C3: choose ONE sketch, then repeat for each remaining part:
arduino-cli upload --fqbn esp32:esp32:esp32c3:CDCOnBoot=cdc --port COM_C3 --input-dir ./firmware/.build/neopixel_test ./firmware/bench/neopixel_test
arduino-cli monitor --port COM_C3 --config baudrate=115200
```

For microphone or IR, replace both neopixel_test path components with mic_level
or ir_test. Close the monitor before uploading another sketch. For native USB
S3 use the same CDC-enabled FQBN used when compiling. Arduino IDE is also fine:
open the matching .ino, select the options above, upload, and use Serial Monitor
or Serial Plotter at 115200. If C3 upload fails, hold BOOT while plugging in.

## Tests and reports

### 1. Servos (S3)

- Pan signal GPIO1; tilt GPIO2. S3 5V/GND feeds the rails, both servo power leads
  connect to those rails, shared ground. C2 and C1 are 470uF, correct polarity,
  at the S3 feed and servo headers. Follow the hardware team's wiring plan.
- Clear the bracket before powering up. Initial centre command may move an
  unknown physical position. Sketch waits 5 seconds after its startup logs,
  attaches both servos, centres them, then moves 1 degree every 40ms.
- Pan sweeps 30..150..90 while tilt holds90, then tilt sweeps while pan holds90.
  Mechanical clearance must support those angles; lower SAFE_MIN/MAX if needed.
- It stops centred; send lowercase r (any newline setting) to repeat.
- After separate motion succeeds, flash .build/servo_sweep_both using the same
  sketch/upload command to exercise BOTH_TOGETHER=1. Both move in that variant.
- Report: each servo smooth? Centre correct? Minimum S3 5V reading while BOTH
  move (target above approximately 4.6V), any jitter/reset and boot reset reason.
- Resets: check cable/capacitor polarity and revert to separate motion. Jitter:
  verify shared ground and breadboard rail continuity, then try another servo.

### 2. NeoPixel (C3)

- GPIO7 -> 330 ohm -> DIN; VCC5V and shared GND. One external pixel, not the
  board's onboard RGB LED. Brightness capped40/255. COLOR_ORDER defaults NEO_GRB.
- Repeating sequence logs every state: ready green; heard blue300ms then green;
  tracking cyan; nosubject amber slow blink; saved white300ms then green;
  error red twice then green; reconnect purple slow blink; sleep off.
- Report each colour/pattern. If red/green swap, change COLOR_ORDER to NEO_RGB
  at the top of the sketch, recompile and reflash, then report the working order.
  These simple bench delays are deliberate; F3 production timers will be nonblocking.

### 3. Microphone (C3)

- INMP441 VDD3V3, GND, SCK4, WS5, SD6, L/R tiedGND; wires short (under20cm).
- 16kHz, 32-bit mono slots, left channel; 800 samples per ~50ms window.
  SHIFT14 converts to signed16-bit with saturation. Output rms,peak is in int16
  units, not calibrated sound pressure. Open Serial Plotter after startup text.
- Speak then remain quiet. Report silence/speech RMS and peak; speech should
  clearly rise. Persistent peak32767/32768 suggests clipping: increase SHIFT,
  rebuild, and report the resulting value. This sketch saves no audio.
- Flat/zero: verify wiring/LR ground. Temporarily change MIC_SLOT to
  I2S_STD_SLOT_RIGHT only to diagnose a channel mismatch; report it rather than
  silently changing the intended left-channel wiring. I2S errors log their code.

### 4. IR (C3, optional)

- Sensor VCC3V3/GND, OUT GPIO1. It must drive OUT; no internal pull assumed.
- Logs initial raw level, debounced changes, active state and hold time on release.
  IR_ACTIVE_LOW=1 is provisional; verify near/far raw levels before accepting it.
- Report raw level far/near, active polarity, and held_ms for a roughly1s hold.
  Change IR_ACTIVE_LOW to0 only if actual module output requires it. If IR is
  omitted, mark skipped/optional; this does not block the required three parts.

## Return this summary

```text
Board/connector/COM ports:
Compile results (four sketches + BOTH_TOGETHER):
Servo pan/tilt smooth; minimum both-moving 5V; resets/jitter:
NeoPixel colours/patterns; working COLOR_ORDER:
Mic silence/speech RMS+peak; working SHIFT; channel:
IR near/far raw levels; polarity; hold time (or omitted):
Remaining F0 setup facts / camera PWDN+RESET documentation:
Failures and Serial logs:
F1 DONE (only when real-part checks pass)
```

Live Wi-Fi/IP checks follow F2/F3 firmware, not these bench programs.
HARDWARE_PLAN.md is absent from this checkout: the hardware team should supply
it before relying on the plan's named wiring phases. No firmware gate is passed
just because these sketches compile; hardware observation is still required.

## 🛑 GATE F1 — Bench tests on real parts

**Print this and wait for `F1 DONE`** (the hardware team can answer in pieces as parts are wired):
- [ ] **Servo sweep:** S3 5V/GND on the breadboard rails with C2 and C1 fitted, pan servo on GPIO 1, tilt on GPIO 2. Tell me when it's plugged in, and I'll flash `servo_sweep`. Does each servo sweep smoothly? What does the S3's 5V pin read while both move (target: above about 4.6V)?
- [ ] **NeoPixel:** DIN → 330 Ω → GPIO 7, 5V, GND. Flash `neopixel_test`. Do the colours match their names? (If red and green are swapped, I'll switch the colour order.)
- [ ] **Mic:** INMP441 wired per §1, L/R to GND, short wires. Flash `mic_level`. Does the plotter jump when you talk and stay near flat in silence?
- [ ] **IR (optional):** flash `ir_test`. Does it trigger when your cheek comes within a few cm?

**Troubleshooting**
| Symptom | Fix |
| --- | --- |
| S3 resets during sweep | Shorter/thicker USB cable; check capacitor polarity; test `BOTH_TOGETHER 0` |
| Servo jitters at rest | Shared ground; split breadboard rail; try a different servo |
| Mic flat / zeros | L/R floating, SCK/WS/SD swapped, wrong slot (try right channel to confirm) |
| Mic clipping | Increase `SHIFT` |
| C3 won't flash | Hold BOOT while plugging in, then upload |
| No Serial on C3 | Enable USB CDC On Boot |

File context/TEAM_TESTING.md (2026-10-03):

# Phase 3 software: team testing handoff

Software is implemented and automated tests pass (98). Live spoken end-to-end
acceptance is unconfirmed. Sharing this version is for testing; Phase3 is not
marked complete and hardware gates remain in force. Physical hardware is tested
by the hardware team/Session B, not on the development laptop.

## Setup on a laptop

Pull main after the user pushes the software commit. From the repository root,
follow README Phase1/2 model setup and install requirements-laptop.txt. Local
.venv, models, photos and logs are ignored and are NOT included in the push.
ONNX YOLO export needs the separate requirements-export.txt environment; runtime
needs models/yolov8n.onnx, models/face_detection_yunet_2023mar.onnx and the Vosk
small English model. Do not install export dependencies on Uno Q.

Run `.\.venv\Scripts\python.exe -m pytest -q` and expect98 passing tests.
Use `.\.venv\Scripts\python.exe -m tools.demo_voice --list-devices` to select an
actual microphone. Device4 was the developer's boAt headset; choose the team's
own device ID rather than assuming4.

## Laptop mock acceptance (no physical NeoPixel required)

Run these in three terminals from the repository root:

```powershell
.\.venv\Scripts\python.exe -m tools.mock_camera
.\.venv\Scripts\python.exe -m tools.mock_voice_unit --device <MIC_ID>
.\.venv\Scripts\python.exe -m app.main --mock --preview
```

Wait for "Mock camera ready" before starting the app; webcam opening may take
several seconds. Wait for app "Ready". Say camera track person, move left/right,
then camera shoot. Check that crop/box follows, offsets/angles change, a newest
photo appears at http://localhost:8080, opening it shows full resolution, and
voice mock prints Light: saved (white flash). This last item is a software print,
not a requirement for a LED on the laptop. PressQ and Ctrl+C in mocks to stop.
Test camera burst (3 photos), camera timer (3 blue-flash prints then photo),
manual moves/centre, stop tracking, and sleep/wake as additional functional checks.

Return which checks passed, OS/mic device name, any traceback, and whether the
photo appeared. Avoid sharing private photos/audio or credentials in context.

## Real boards and gates

Session B/hardware team follows FIRMWARE_PLAN.md for physical INMP441/C3 audio,
NeoPixel, camera, servos and firmware checks. No firmware change is part of this
software commit. SOFTWARE_PLAN.md Gate0 must be explicitly satisfied before
Phase5 UnoQ deployment; real S3/C3 integration belongs to later gates/phases.
Current config IPs are examples, not confirmed addresses. Never guess pins or
replace IPs using an unverified interface address. Wire contract remains HTTP
control80/stream81, UDP audio5005/lights5006 and gallery8080.

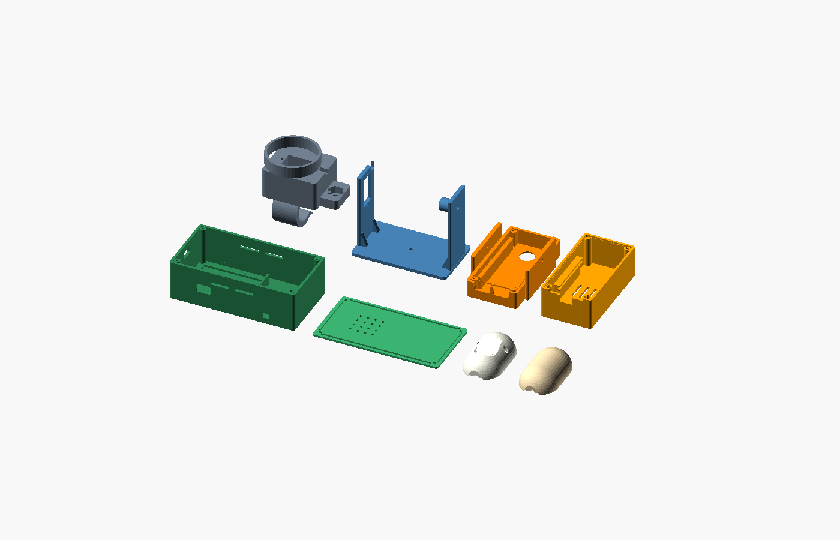
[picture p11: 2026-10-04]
enclosure/validation/layout.png

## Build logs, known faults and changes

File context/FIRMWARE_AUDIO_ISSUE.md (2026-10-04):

# C3 audio delivery: suspected blocking USB status logging

Session A diagnosis, 2026-10-04. Firmware implementation remains Session B owned.

Observed production firmware: `voice_unit/voice_unit.ino` prints packet counters
with `Serial.printf` from `audioTask()` every10s (around line116). Build is
ESP32-C3 with CDCOnBoot=cdc, installed Arduino ESP32core3.3.11.

Controlled observations with current board/IPs and unchanged firmware:
- Hotspot awake/nearby, serial closed:533packets/20.02s,26.62/s,maxgap2.374s.
- Simultaneous serial reader open and receiver40s:1258packets/40.056s,
  31.41/s,maxgap0.555s. C3 counters at10.042/20.040/30.088/40.091s were
  79816/80129/80442/80755 (313between reports),send_errors7026 unchanged.
- Close serial reader and repeat:576packets/20.024s,28.77/s,maxgap2.265s.
- No malformed packets or kernel UDP receive-buffer/checksum errors in these runs.
- UnoQ power-save off earlier did not resolve the2s pauses; original ON restored.

Installed `cores/esp32/HWCDC.cpp` has tx_timeout_ms=100 and
max_consec_timeouts=20; write() comments describe host backpressure even with
USB physically connected. Logging from the producer task plus matching pause
lengths and open/closed comparison strongly support USB logging as cause.
This is an inference, not a completed firmware fix. Exact packet loss cannot be
reconstructed because contract packets have no sequence numbers.

Session B action: make status/debug output nonblocking so audio never waits for
USB host consumption. Review all Serial calls (audio error/counters, loop/light/
disconnect reporting); choose correct APIs for this exact core and keep the
16kHz/512sample/rawPCM contract unchanged. Do not suppress acceptance failures,
raise jitter buffering to hide them or change gain without microphone evidence.
Compile, then obtain upload authorization as required by firmware workflow.

Acceptance after fix: repeat >=40s reception with USB attached but serial reader
closed, then with C3 USB power only/no data if practical; record rate/gaps/kernel
errors. Run original5s voice-unit checker and actual WAV clarity/NeoPixel tests,
then real UnoQ voice directions/tracking/shoot/phone gallery. Temporary open-
monitor testing is diagnostic only; standalone robustness remains unpassed.

Evidence (private ignored logs): c3-hotspot-awake.json,c3-udp-serial-open.json,
c3-udp-serial-closed.json,c3-synchronized-sender.log and associated console logs.
No firmware file edited/reflashed by Session A during this diagnosis.

## Fresh receiver-side reproduction - 2026-10-04
User requested testing after e0d66c4. Unchanged canonical5second checker on Uno Q
passed format/rate threshold:166packets,0malformed,RMS151.4,peak1443. Private WAV
played; user clarity and light observation pending. With serial monitor closed,
new40.033second metadata-only sample received1072packets/26.78persecond,
0malformed,max gap2.513seconds,12gaps over250ms. No payloads saved for long check.
This reproduces the pauses; no logging fix/flash or fresh serial-open comparison
performed. Firmware B action and standalone closed-monitor acceptance above
remain pending. See ignored logs/c3_f3_test/delivery-serial-closed.json.

## Repair prepared, not yet hardware-verified — 2026-10-04
voice_unit now queues logs with zero-wait enqueue and drains only in main loop
when USB has space; CDC timeout0. Compile passed999975 program/37976 globals.
Not flashed under user's hardware deferral. The previous2.513s gap remains the
last sustained physical evidence. Next: flash with confirmed board connection,
then repeat >=40s delivery with serial CLOSED before claiming resolution.

## C3 logging repair flashed - 2026-10-04
User explicitly requested “flash c3”. Arduino discovery found COM18 ESP USB;
esptool identified ESP32-C3 AZrev1.1,4MB,MAC44:b1:76:17:f5:7c before writing.
Uploaded the previously compiled999975-byte repair using esp32:esp32:esp32c3:
CDCOnBoot=cdc. Upload exited0, written hashes verified, hard reset completed.
Startup confirmed mic4/5/6,pixel7,SHIFT14,IR omitted,TX8.5dBm,DHCP IP
10.153.76.243,RSSI -50dBm,audio destination10.153.76.45:5005,light listener5006.
Brief serial checks showed packets_sent98/167/192 but send_errors118/362/650:
send failures are increasing, so delivery is NOT established and this is NOT
F3 acceptance. No receiver, speech/LED observation or >=40s closed-monitor
delivery test was run. Root cause of send errors is unverified; confirm Uno Q
destination availability/network path when user resumes hardware testing.
Serial readers closed after checks; S3/Uno Q not flashed or controlled and
service not enabled. Hardware remains deferred except this requested upload.
Ignored logs:firmware/.build/voice-unit-nonblocking-upload.log and startup.log
(full startup filename:voice-unit-nonblocking-startup.log).
Existing HEAD d64f754f219d4b983a32bd87f740309fc2920e41 is published on origin/main.
No new commit/push requested for this flash. Exact next action: diagnose C3 UDP
send failures with the verified destination available, then closed-monitor
sustained delivery and speech/light checks; measure S3 power-bank feed under
servo load before combined physical acceptance. Preserve pending gates.

## Later outage evidence - 2026-10-04
Latest Session B repair is compiled but not flashed. Following freeform test
missing-audio warning, stopped-app receiver got38validpackets/20.351s (1.87/s),
14.374s gap,zero malformed/receive/checksum/buffererrors. Both ESP32 USB ports
currently absent;sender Serial counters unavailable. User says boards stayed
powered. Do not attribute all this deficit to old logging without new evidence.
Flash/retest remains Session B owned;no Session A firmware changes.

## Camera and microphone repair investigation - 2026-10-04

User authorized fixing delivery issues. Vision remains stopped; no movement,
capture, light command, firmware modification, flash or service activation.
Session A ownership remains in force. Latest Session B handoff confirms the C3
queued-logging repair WAS FLASHED successfully on COM18. Earlier Session A
notes saying unflashed are superseded. User confirms hotspot close and awake,
battery saver off. Uno Q remains 10.153.76.45, S3 .67, C3 .243; MACs verified
through Uno Q neighbours. ADB serial 662499217; C3 COM18 is present again.

Actual stopped-app measurements after repair:
- C3 serial-closed 20.081s: 601 valid packets, 29.93/s, max gap 1.070s,
  zero malformed/other-source/kernel receive or checksum errors.
- S3 stream-only 21.095s: 87 frames, 4.12 received FPS, max chunk gap .937s,
  status latency .534s, RSSI -39, uptime 788s. No HTTP errors. Diagnostic ok
  means delivery occurred, not stable tracking or physical acceptance.
- C3 active receiver + serial open 40.057s: 1036 valid packets, 25.86/s,
  max gap 1.420s, zero malformed or kernel receive errors. Sender counters
  increased from sent15353/errors6147 to sent16076/errors6363 across three
  10-second reports, then sent16389/errors6363 on the next report. Send failures
  persist with an active destination; not simply a missing receiver or old
  blocking producer logging. Their exact stage/errno remains unknown.
- Uno Q ping averages: C3 380ms (max1072), S3 373ms (max829), hotspot130ms.
  Laptop also sees C3 delays up to1119ms and one timeout in five probes.
  Strong RSSI does not establish a responsive path. Network/firmware attribution
  still unresolved; no power problem inferred solely from these measurements.

Temporary Wi-Fi comparison launched in a local console; sudo authentication
is pending. No power setting changed yet. Baseline 633/20.011s =31.63/s,
max gap .620s, zero receive errors. It will test power saving off and restore
original ON through an EXIT trap; no permanent profile edits. First attempt
failed due to CRLF in an ignored script; corrected LF and restarted. Existing
result JSON from first attempt is stale while new test waits. No secrets saved.

Evidence is metadata under ignored logs/: c3-repair-receiver.json,
c3-repair-sender.log, repair-camera-baseline.json, unoq-wifi-repair-console.log.
Software freshness race fix from preceding turn remains deployed; 136 tests
passed then, not rerun here because production source is unchanged this turn.
Current HEAD d64f754f219d4b983a32bd87f740309fc2920e41. No commit/push requested.
Acceptance and benchmark remain pending. Next: complete authenticated network
comparison, evaluate measured effects, and report any remaining sender firmware
fault to user for Session B. Do not increase freshness/buffer limits to hide gaps.

## New-network uploads completed; S3 connection blocker - 2026-10-04

User explicitly authorized this Session A to compile/upload EXISTING sketches
and update network addresses only, overriding the normal Session B boundary
for this narrow task. No sketch implementation changed. Verified chips/MACs
before writing: C3 COM18 ESP32-C3 AZrev1.1/44:b1:76:17:f5:7c; S3 COM19
ESP32-S3 rev0.2/28:84:85:a1:85:ec. User-edited secrets initially did not match
laptop SSID exactly. Corrected SSID in both ignored headers to the observed
network, preserved user passwords, set C3 UNOQ_IP172.20.10.2. Both passwords
compared equal without printing values. DHCP1 retained; no guessed static IPs.

Both final builds succeeded: C3 999979 program/37976 globals; S3 984997/56656.
Both final uploads exited0, flash hashes verified and boards reset. Pins,
servo/camera/microphone conversion/light behavior/shared contract unchanged.
Source diff confirms neither sketch edited. Secret headers still Git-ignored.
One earlier successful upload had the nonmatching SSID; final uploads replace it.

Uno Q now on new iPhone network, DHCP172.20.10.2/28, gateway172.20.10.1;
laptop172.20.10.3. Uno Q fell back to old network once during uploads; manually
reactivated verified new profile and rechecked it remains new. Do not assume
future reconnections keep this DHCP destination; verify before later uploads.
C3 joined172.20.10.4; MAC confirmed by neighbour and serial boot. LightUDP5006
ready, audio destination172.20.10.2:5005. Ping averaged24ms in3 probes, but
sustained serial-CLOSED receiver40.132s got only388 packets (9.67/s), max gap
9.517s, zero malformed/other-peer/kernel receive errors. New network has NOT
resolved audio delivery. Source sender/network causal attribution still pending.

S3 has NOT joined; no confirmed new IP. Serial repeated Wi-Fi state changes
and E wifi:Set status to INIT after upload and after one authorized restart.
Camera/PSRAM/OV3660 initialization succeeds; latest boot reset_reason1 is
explicit tool reset, not a new inferred spontaneous brownout. No fresh BOD
message captured. User says iPhone Maximize Compatibility already enabled;
scan reports hotspot2437MHz. Password equality alone does not identify fault.
No extra connection behavior change authorized under network-only exception.
Asynchronous question asks user to authorize Wi-Fi diagnostics/connection fixes
here or hand remaining firmware issue back to Session B. Await decision.

Root config.yaml and ignored full-system config have UnoQ172.20.10.2 and
C3172.20.10.4. S3 field still OLD10.153.76.67; NOT ready for full runtime.
Launch console URL updated172.20.10.2:8080/live; app remains STOPPED, no full
new-network run or camera comparison claimed. Local config validation passed;
prior136 software tests not rerun for configuration/build-only changes.
Ignored logs hold build/upload/serial and new-network-c3-delivery.json metadata;
no speech WAV/media or credentials included in handoff. Serial readers closed.

No commit/push or service activation. Existing HEADd64f754. All physical
acceptance/CPUbenchmark pending. Exact next action: resolve Wi-Fi diagnostic
ownership, diagnose S3 association and C3 gaps, verify S3 IP by MAC/status,
finish runtime config/deployment, then run requested unrestricted live test.
Respect user no guided voice sequence and no time limit. Update context before
any future commit; preserve both sessions' records.

## New-network real-component run active; lag persists - 2026-10-04

User requested migration, all IP updates and another unrestricted real run.
User explicitly authorized two Session A exceptions: network-only secret/settings
build/upload, then Wi-Fi diagnostics/connection fixes. This does not authorize
unrelated firmware features/pins/contract edits or future phases. Corrected both
ignored SSIDs to verified laptop network, preserved user-entered passwords,
set C3 UNOQ_IP172.20.10.2, retained DHCP. Secrets remain ignored, not printed.
Verified chip/MAC/ports before upload. C3 final compile999979/37976 bytes,
S3 final compile986161/56664; final uploads exit0 with verified flash hashes.

S3 initially could not join. Added bounded disconnect reason/count reporting
(13 source lines; callback only updates counters, main reports at most2s).
Temporary S3 TX8.5dBm cap did NOT solve association; removed and flashed final
build with original transmit power. No other sketch behavior/pins/capture/audio
conversion/lights changed. New reporting revealed reason5 (ASSOC_TOOMANY,
access point unable to handle associated clients). Controlled test disconnected
ONLY Uno Q Wi-Fi while USB remained: S3 immediately joined172.20.10.5, whereas
Uno Q then failed rejoin. User says only laptop/UnoQ/C3 were connected. This
supports hotspot capacity in this observed setup, not a universal iPhone limit.
User moved laptop back to Jasil after Windows location policy blocked CLI switch.
Uno Q then rejoined successfully; all three board MACs reachable on new network.

Current verified board IPs: Uno Q172.20.10.2/28, C3172.20.10.4, S3172.20.10.5;
gateway172.20.10.1. Root config.yaml AND remote root/full-system config updated.
Laptop is on previous network and does not occupy new-hotspot slot. USBADB
662499217 forward tcp8080 -> UnoQ tcp8080 provides http://localhost:8080/live.
Application computation still entirely Uno Q; USB/laptop only console/live view.
Direct gallery on new network http://172.20.10.2:8080 (phone access unconfirmed).
ADB forwarding must be recreated after disconnect/device restart; no auto-start.

New-network delivery checks, serial monitors CLOSED, no capture/move/light:
Initial C3-only40.132s:388 valid packets,9.67/s,maxgap9.517s; not repaired.
After three boards could join, concurrent40s C3 + camera: C3993/40.010s,
24.82/s vs31.25expected,maxgap.639s,0malformed/kernel receive errors. Camera
20frames over13.065s,1.53receivedFPS,maxchunkgap1.197s,status1.106s; requested40s
ended early with2s readtimeout. Diagnostic okfalse. Changing network has NOT
eliminated delivery issues; these are network measurements, not CPU benchmark.
No claim of exact loss, smooth motion, WAV clarity, colours or full acceptance.

Requested app launched successfully, actual PID14195, UDP5005 owned by app,
--mic udp --seconds0 and real full-system config. USB /live and /live/frame.jpg
HTTP200; browser opened localhost live URL. Startup/calibration and camera sync
completed; repeated freshness warnings still observed. Accepted camera up at
08:04:15(board log clock); physical action not yet confirmed. No guided commands,
voice injection or automatic tracking; user chooses commands. Run continues
until user stops, no expiry or service activation. All diagnostics/readers ended.

Ignored logs retain final builds/uploads, serial association evidence, new-
network-camera-delivery.json and new-network-c3-delivery.json. Configuration
validation passed locally and on Uno Q. Prior136 software-test result unchanged;
not rerun for this firmware/network-only work. No commit/push requested. Existing
HEADd64f754; firmware/STATUS/context records updated under explicit exception.
Pending: user live feedback, residual stream/audio diagnosis, power under load,
full19-command/features/phone gallery acceptance, CPUbenchmark and standalone
acceptance. Next: observe freeform results or stop exact owned app on request;
never label network migration a stability pass. Refresh context before any commit.

## Wi-Fi transport follow-up - 2026-10-04

User explicitly authorized Session A network-only compilation/upload and Wi-Fi
connection diagnostics/fixes. Latest changes: C3 bounded transient UDP retries,
S3 TCP_NODELAY and stream timing. Both compiled/flashed with verified hashes.
C3 1000357/37976 bytes; S3 986425/56664. No pins/acquisition/PCM contract change.
Final concurrent sample: C3 27.83 packets/s with 0.867s max gap, no malformed or
kernel UDP errors; S3 2.91FPS, 1.166s max chunk gap, frame wait1ms versus network
send wait1009/1626ms. Delivery remains unstable; no F2/F3 or software acceptance.
Uno Q172.20.10.2, C3.4, S3.5; laptop on Jasil using USB localhost:8080/live.
Runtime stopped, all bounded diagnostics ended; no automatic restart or commit.
Next controlled access-point comparison requires verified new network settings;
do not assume changing hotspot alone fixes board RF/power/transport behavior.
Root HANDOFF/TESTING records contain exact evidence and outstanding acceptance.

## TinkerSpace router migration pending - 2026-10-04

User selected TinkerSpace; Uno Q verified192.168.1.99 and S3192.168.1.122,
WPA2 2.4GHz. Both ignored credentials updated, C3 audio destination192.168.1.99.
C3 still fails association; its DHCP address unknown. C3 default TX power and
manual45s reconnect comparison compiled1000105/37976/flashed verified; S3
986425/56664/flashed verified. No physical/PCM/capture contract change.
S3 HTTP probes failed with0frames; no concurrent audio probe/full run possible.
Runtime stopped; root/runtime config still old hotspot values, DO NOT launch.
Root HANDOFF/TESTING has exact diagnostics and next steps for Session B/router
association investigation, verified config completion and metadata retest.
No commit/push or gate completion; all bounded diagnostics/readers ended.

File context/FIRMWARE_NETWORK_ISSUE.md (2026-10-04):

# Wi-Fi transport diagnostic handoff - 2026-10-04

No root cause or successful fix established. Current symptoms occur below the
Vision app: C3 fails association and S3 HTTP/frame delivery stalls. Do not mark
software phases or firmware F2/F3 passed. Session A had explicit network-only
Wi-Fi diagnostic/build/upload exceptions; broader firmware remains Session B.

## Verified tests

- Uno Q active TinkerSpace WPA2,2462MHz,192.168.1.99; S3 earlier joined
  192.168.1.122/MAC28:84:85:a1:85:ec. C3 DHCP unknown; never inferred.
- C3 temporary Wi-Fi-only sketch (no I2S/NeoPixel software initialization):
  standard b/g/n20s and b/g30s both failed association, disconnectreason2.
- Second C3 isolation: scanner saw the exact router BSSID90:67:17:02:a6:67,
  channel11,RSSI-64/-62; targeted channel/BSSID connection at8.5dBm then5dBm,
  20s each, failed. No evidence that password is wrong: both ignored credentials
  matched locally stored active Uno Q profile, including unescaped comparison.
- C3 diagnostic softAP reported AP_READY192.168.4.1/channel1. Uno Q could not
  find Vision-C3-Diagnostic; directed rescan/full rescan still did not list it.
  This implicates radio/calibration/driver or RF/power path, not a confirmed
  board defect. Needs spare-board or driver/PHY comparison to distinguish causes.
- Uno Q powersaveOFF router test:0frames/4158bytes, maxgap3.871s,status1.886s,
  readtimeout; actualradioON/savedprofiledefault0 restored and verified.
- S3 b/g comparison:1frame/4.750s, status0.963s, streamreadtimeout. Reverted
  protocol experiment; original b/g/n production rebuilt986425/56664/flashed
  with verified hashes. No sensor/pins/servo/capture protocol changes.
- User says hotspots off, boards close/clear antennas, alternate cable/power
  ready. Post-report production C3 retry50s still no IP/three reason2 events;
 20s UDP metadata discovery returned no peers. Cannot independently verify
  physical wiring or power changes. S3 post-hotspot-off probe0frames/status and
  streamconnecttimeouts; later ping1/3 replies,551ms. No single cause proven.

## Restoration and next action

Both temporary C3 isolation/access-point sketches were removed from the board
by production upload1000105/37976. Production keeps prior SDK-default TX power,
manual45s reconnect and bounded audio-send retry; no new production C3 feature.
S3 protocol comparison reverted. Uno Q restored TinkerSpace, temporary diagnostic
NM profile deleted, credential-bearing remote test helper self-deleted.
All serial readers/probes ended; Vision stopped. Root/runtime config still old
hotspot addresses: do not launch until all verified board IPs are updated.
No commit/push. Existing HEADd64f754f219d4b983a32bd87f740309fc2920e41.

User asked find/fix. Asked whether spare C3 available; comparison pending. If
available, identify exact connected replacement port/MAC before any flash,
repeat Wi-Fi-only association/AP comparison, then restore production. If not,
Session B should compare driver/PHY calibration on this board and hardware team
check unloaded supply/RF; router administrator can check association/MAC-filter
logs. Do not erase flash/NVS or guess pins as an unapproved diagnostic shortcut.
Camera transport remains independently unresolved and needs retest afterward.
Prior136 software tests are last result; not rerun during network isolation.

## Metadata evidence (ignored logs; no private media)

c3-wifi-isolation-result.log; c3-wifi-isolation-power-result.log;
c3-wifi-ap-start.log; router-c3-new-power-check.log;
router-camera-powersave-off.json; router-camera-bg.json;
router-camera-hotspots-off.json; router-s3-restored-compile/upload logs;
router-c3-final-production-upload.log. Temporary diagnostic builds/uploads also
ignored. Official reason2 interpretation: authentication response timeout,
https://docs.espressif.com/projects/esp-idf/en/release-v5.4/esp32/api-guides/wifi.html
Search found older driver reports, not a verified matching3.3.11 fix; no SDK
upgrade/downgrade performed.

## BLE comparison - 2026-10-04

C3 BLE trial delivered loss-free PCM in final40s (0padding), while Wi-Fi still
fails authentication. This establishes useful BLE throughput on this board; it
does not prove the Wi-Fi root cause or complete full acceptance. Maximum101ms
notification gap exceeds strict100ms threshold. S3 concurrentprobe still0frames/
timeout. See BLE_TRANSPORT.md and latest HANDOFF. Furtherfirmware work belongsB.

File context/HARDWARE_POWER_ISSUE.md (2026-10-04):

# S3 power brownouts during real tracking - 2026-10-04

Actual `logs/vision-COM19.log` contains repeated `E BOD: Brownout detector was
triggered`, followed by ROM boot/reinitialization. Recent sequence includes
stream open + moves52/79,52/80,52/82, then brownout; later stream open + move48/82,
then another brownout. Voice command was accepted on Uno Q; camera stream and
/move then timed out because board repeatedly reset/unavailable. The precise
weak supply/cable/connection/load remains unmeasured; don't guess its component.

Official Espressif meaning: brownout detector resets chip when supply falls
below safe level (https://docs.espressif.com/projects/esp-idf/en/release-v5.2/esp32s3/api-guides/fatal-errors.html).
No firmware edit/flash or brownout-detector bypass done. No timeout increase.

Hardware-team next action follows SOFTWARE_PLAN Gate A:
- Verify S3/servo shared ground, continuous rails and sound power connections.
- Check short/thick USB feed from planned supply, C2 470uF by S3 feed and C1
  470uF by servo headers, correct polarity, and mechanically free bracket.
- Measure S3 5V pin under both-servo load; project acceptance about >=4.6V.
  This project feed criterion is not the chip's internal brownout threshold.
- Report actual supply topology/measurement; correct hardware first, then repeat
  controlled camera/motion/stream checks with no reset and resume live tracking.

User's current power topology requested asynchronously, reply pending. Stop
integration until corrected; earlier Gate A readiness does not negate observed
failure. Existing software source129tests pass, physical acceptance now failed.

Runtime already ended with Ctrl+C/exit0 when checked; app/8080/5005 absent.
Signaled owned serial readers to stop; no background auto-restart configured.
C3 standalone USB logging issue is separate in FIRMWARE_AUDIO_ISSUE.md.

## Confirmed supply description correction - 2026-10-04
User reports power bank -> S3 USB -> S3 5V/GND -> both servos. The initial
PD-charger description was corrected. Servos share S3 ground and USB power path.
Current voltage stability/brownout recurrence is untested; cause unresolved.
No new hardware check or wiring change. Measure under camera/both-servo load
when testing resumes; do not infer a defective power bank from old reset logs.

## Later power topology and spontaneous restart - 2026-10-04
Latest user correction in shared handoff:powerbank feedsS3USB,servos fromS35V/GND.
Latest freeform outage endedafterminutes;user denies unplug/restart/hotspotchange.
Subsequentuptime146/reset_reason1 confirmsrestart,butfreshSerial unavailable
(S3COM19absent). Existingbrownoutevidence is historical,not proof of this reset
cause. Stopped-app stream4.33FPS/maxgap1.671s;notstabletrackingacceptance.

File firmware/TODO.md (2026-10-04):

# Future firmware features

- [ ] Optional IR head/cheek photo trigger on the C3 SuperMini, OUT GPIO1.
  Deferred by user on 2026-10-04; omitted from this prototype.
  Before enabling: confirm sensor wiring and active polarity with ir_test;
  hold at least 1 second to send ASCII shoot to Uno Q UDP5007, with a 2-second
  lockout. Verify unintended-trigger rejection and the physical head/cheek
  placement with the user. Preserve the shared interface contract.

Prototype scope: voice-triggered photos, camera/servo control, mic and NeoPixel.
Future voice firmware should default USE_IR=0 for this prototype. The existing
ir_test bench sketch is retained for later validation; it has only been compiled,
not physically tested. Re-enable IR only on a future user request.

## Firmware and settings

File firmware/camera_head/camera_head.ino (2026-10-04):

#include <Arduino.h>
#include <WiFi.h>
#include <ESP32Servo.h>
#include <esp_camera.h>
#include <esp_http_server.h>
#include <esp_heap_caps.h>
#include <esp_system.h>
#include <errno.h>
#include <lwip/sockets.h>
#include "camera_pins.h"
#if __has_include("secrets.h")
#include "secrets.h"
#else
#include "../secrets.example.h"
#endif
#ifndef WIFI_USE_DHCP
#define WIFI_USE_DHCP 0
#endif
#define PAN_MIN 10
#define PAN_MAX 170
#define TILT_MIN 40
#define TILT_MAX 140
constexpr uint32_t SERVO_INTERVAL_MS = 20;
constexpr int SLEW_DEG = 2;
constexpr uint32_t STREAM_INTERVAL_MS = 100;  // At most 10 fps; leave airtime for control.
Servo panServo, tiltServo;
SemaphoreHandle_t cameraMutex, servoMutex;
volatile bool capturePending = false;
volatile bool photoSending = false;
int targetPan = 90, targetTilt = 90, actualPan = 90, actualTilt = 90;
uint32_t moveReceivedMs = 0, moveSettledMs = 0;
volatile uint32_t wifiDisconnects = 0;
volatile uint16_t wifiDisconnectReason = 0;
bool moveInProgress = false;
uint8_t *heldPhoto = nullptr;
size_t heldLength = 0;
framesize_t captureSize = FRAMESIZE_QXGA;
httpd_handle_t controlServer = nullptr, streamServer = nullptr;

class CameraLock {
 public:
  bool acquired;
  explicit CameraLock(uint32_t ms) : acquired(xSemaphoreTake(cameraMutex, pdMS_TO_TICKS(ms)) == pdTRUE) {}
  ~CameraLock() { release(); }
  void release() { if (acquired) { xSemaphoreGive(cameraMutex); acquired = false; } }
};
class ServoLock {
 public:
  bool acquired;
  explicit ServoLock(uint32_t ms) : acquired(xSemaphoreTake(servoMutex, pdMS_TO_TICKS(ms)) == pdTRUE) {}
  ~ServoLock() { release(); }
  void release() { if (acquired) { xSemaphoreGive(servoMutex); acquired = false; } }
};
void fatal(const char *message) {
  Serial.printf("FATAL %s; stopped. Correct configuration and reset.\n", message);
  while (true) delay(1000);
}
esp_err_t errorReply(httpd_req_t *req, const char *status, const char *message) {
  char text[180];
  snprintf(text, sizeof(text), "{\"error\":\"%s\"}", message);
  httpd_resp_set_status(req, status);
  httpd_resp_set_type(req, "application/json");
  return httpd_resp_send(req, text, HTTPD_RESP_USE_STRLEN);
}
esp_err_t jsonReply(httpd_req_t *req, const char *text) {
  httpd_resp_set_type(req, "application/json");
  httpd_resp_set_hdr(req, "Cache-Control", "no-store");
  return httpd_resp_send(req, text, HTTPD_RESP_USE_STRLEN);
}
bool parseAngle(const char *query, const char *key, int low, int high, int &result) {
  char value[24];
  if (httpd_query_key_value(query, key, value, sizeof(value)) != ESP_OK) return false;
  char *end;
  errno = 0;
  const long angle = strtol(value, &end, 10);
  if (errno || end == value || *end) return false;
  result = angle < low ? low : angle > high ? high : static_cast<int>(angle);
  return true;
}
esp_err_t moveHandler(httpd_req_t *req) {
  const uint32_t received = millis();
  char query[96];
  int pan, tilt;
  if (httpd_req_get_url_query_str(req, query, sizeof(query)) != ESP_OK ||
      !parseAngle(query, "pan", PAN_MIN, PAN_MAX, pan) ||
      !parseAngle(query, "tilt", TILT_MIN, TILT_MAX, tilt))
    return errorReply(req, "400 Bad Request", "pan and tilt must be integers");
  // A stalled camera frame must not delay a manual target or servo PWM update.
  ServoLock lock(100);
  if (!lock.acquired) return errorReply(req, "503 Service Unavailable", "servos busy");
  targetPan = pan; targetTilt = tilt;
  moveReceivedMs = received;
  moveInProgress = actualPan != targetPan || actualTilt != targetTilt;
  moveSettledMs = moveInProgress ? 0 : received;
  char text[64];
  snprintf(text, sizeof(text), "{\"pan\":%d,\"tilt\":%d}", targetPan, targetTilt);
  lock.release();
  Serial.printf("move accepted pan=%d tilt=%d received_ms=%lu handler_ms=%lu\n", pan, tilt,
    static_cast<unsigned long>(received), static_cast<unsigned long>(millis() - received));
  return jsonReply(req, text);
}
esp_err_t statusHandler(httpd_req_t *req) {
  CameraLock lock(2000);
  if (!lock.acquired) return errorReply(req, "503 Service Unavailable", "camera busy");
  ServoLock servoLock(100);
  if (!servoLock.acquired) return errorReply(req, "503 Service Unavailable", "servos busy");
  char text[448];
  snprintf(text, sizeof(text),
    "{\"pan\":%d,\"tilt\":%d,\"actual_pan\":%d,\"actual_tilt\":%d,"
    "\"move_received_ms\":%lu,\"move_settled_ms\":%lu,\"move_in_progress\":%s,"
    "\"uptime_s\":%lu,\"held_photo\":%s,\"rssi\":%d,\"free_heap\":%u,"
    "\"free_psram\":%u,\"reset_reason\":%d}",
    targetPan, targetTilt, actualPan, actualTilt,
    static_cast<unsigned long>(moveReceivedMs), static_cast<unsigned long>(moveSettledMs),
    moveInProgress ? "true" : "false", static_cast<unsigned long>(millis() / 1000),
    heldPhoto ? "true" : "false", WiFi.RSSI(), static_cast<unsigned>(ESP.getFreeHeap()),
    static_cast<unsigned>(ESP.getFreePsram()), static_cast<int>(esp_reset_reason()));
  servoLock.release();
  lock.release();
  return jsonReply(req, text);
}
esp_err_t ackHandler(httpd_req_t *req) {
  CameraLock lock(2000);
  if (!lock.acquired) return errorReply(req, "503 Service Unavailable", "camera busy");
  if (heldPhoto) { free(heldPhoto); heldPhoto = nullptr; heldLength = 0; }
  lock.release();
  return jsonReply(req, "{\"ok\":true}");
}
void discardFrames(unsigned count) {
  for (unsigned i = 0; i < count; ++i) {
    camera_fb_t *frame = esp_camera_fb_get();
    if (frame) esp_camera_fb_return(frame);
  }
}
esp_err_t captureHandler(httpd_req_t *req) {
  const uint32_t started = millis();
  capturePending = true;
  // Wait for any in-progress servo write before changing camera resolution.
  // The loop rechecks capturePending while holding the same servo mutex.
  {
    ServoLock servoLock(100);
    if (!servoLock.acquired) {
      capturePending = false;
      return errorReply(req, "503 Service Unavailable", "servos busy");
    }
  }
  CameraLock lock(5000);
  if (!lock.acquired) {
    capturePending = false;
    return errorReply(req, "503 Service Unavailable", "camera busy");
  }
  // Retried /capture returns the retained image until /ack.
  if (!heldPhoto) {
    sensor_t *sensor = esp_camera_sensor_get();
    bool captured = false;
    const framesize_t sizes[] = {captureSize, FRAMESIZE_UXGA, FRAMESIZE_SXGA, FRAMESIZE_XGA};
    for (framesize_t size : sizes) {
      if (sensor->set_framesize(sensor, size) != 0) continue;
      delay(100);
      discardFrames(2);
      camera_fb_t *frame = esp_camera_fb_get();
      if (frame && frame->format == PIXFORMAT_JPEG && frame->len > 4 &&
          frame->buf[0] == 0xff && frame->buf[1] == 0xd8) {
        uint8_t *copy = static_cast<uint8_t *>(heap_caps_malloc(frame->len, MALLOC_CAP_SPIRAM | MALLOC_CAP_8BIT));
        if (copy) {
          memcpy(copy, frame->buf, frame->len);
          heldPhoto = copy; heldLength = frame->len; captureSize = size; captured = true;
          Serial.printf("capture %ux%u bytes=%u time_ms=%lu\n", frame->width, frame->height,
            static_cast<unsigned>(frame->len), static_cast<unsigned long>(millis() - started));
        } else Serial.println("ERROR capture PSRAM allocation failed");
      }
      if (frame) esp_camera_fb_return(frame);
      if (captured) break;
      Serial.printf("ERROR capture failed at size=%d; trying lower\n", static_cast<int>(size));
    }
    const int restored = sensor->set_framesize(sensor, FRAMESIZE_QVGA);
    if (restored == 0) discardFrames(2);
    else Serial.println("ERROR restoring QVGA stream");
    if (!captured || restored != 0) {
      if (heldPhoto) { free(heldPhoto); heldPhoto = nullptr; heldLength = 0; }
      capturePending = false;
      return errorReply(req, "503 Service Unavailable", "capture failed; inspect Serial");
    }
  }
  const uint8_t *photo = heldPhoto;
  const size_t length = heldLength;
  capturePending = false;
  lock.release();
  // Single control server task serializes /ack after this response finishes.
  httpd_resp_set_type(req, "image/jpeg");
  httpd_resp_set_hdr(req, "Cache-Control", "no-store");
  // Give still-photo traffic the radio while keeping the servo mutex released.
  // Bounded chunks avoid a single large blocking send from PSRAM.
  photoSending = true;
  esp_err_t sent = ESP_OK;
  for (size_t offset = 0; offset < length && sent == ESP_OK; offset += 4096) {
    const size_t chunk = min(static_cast<size_t>(4096), length - offset);
    sent = httpd_resp_send_chunk(req, reinterpret_cast<const char *>(photo + offset), chunk);
    delay(1);
  }
  if (sent == ESP_OK) sent = httpd_resp_send_chunk(req, nullptr, 0);
  photoSending = false;
  Serial.printf("capture send bytes=%u result=0x%x total_ms=%lu\n", static_cast<unsigned>(length),
    sent, static_cast<unsigned long>(millis() - started));
  return sent;
}
esp_err_t streamHandler(httpd_req_t *req) {
  httpd_resp_set_type(req, "multipart/x-mixed-replace;boundary=frame");
  httpd_resp_set_hdr(req, "Cache-Control", "no-store");
  uint8_t *copy = nullptr;
  size_t capacity = 0;
  esp_err_t result = ESP_OK;
  const int socket = httpd_req_to_sockfd(req);
  Serial.printf("stream open socket=%d\n", socket);
  uint32_t streamFrames = 0, lastStreamLog = millis();
  uint32_t maxFrameWaitMs = 0, maxSendWaitMs = 0;
  while (WiFi.status() == WL_CONNECTED) {
    const uint32_t frameCycleStarted = millis();
    // A viewer may close its receive side while queued video is still writable.
    // Detect FIN promptly so the single stream task can accept the next viewer.
    char pending;
    const int peek = recv(socket, &pending, 1, MSG_PEEK | MSG_DONTWAIT);
    if (peek == 0 || (peek < 0 && errno != EAGAIN && errno != EWOULDBLOCK)) break;
    if (capturePending || photoSending) { delay(5); continue; }
    size_t length = 0;
    {
      CameraLock lock(2000);
      if (!lock.acquired) { result = ESP_FAIL; break; }
      if (capturePending) continue;
      const uint32_t frameStarted = millis();
      camera_fb_t *frame = esp_camera_fb_get();
      maxFrameWaitMs = max(maxFrameWaitMs, millis() - frameStarted);
      if (millis() - frameStarted > 1000) Serial.printf("stream frame wait_ms=%lu\n", static_cast<unsigned long>(millis() - frameStarted));
      if (!frame || frame->format != PIXFORMAT_JPEG) {
        if (frame) esp_camera_fb_return(frame);
        Serial.println("ERROR stream frame unavailable"); result = ESP_FAIL; break;
      }
      if (frame->len > capacity) {
        uint8_t *grown = static_cast<uint8_t *>(heap_caps_realloc(copy, frame->len, MALLOC_CAP_SPIRAM | MALLOC_CAP_8BIT));
        if (!grown) {
          esp_camera_fb_return(frame); Serial.println("ERROR stream PSRAM allocation failed");
          result = ESP_ERR_NO_MEM; break;
        }
        copy = grown; capacity = frame->len;
      }
      length = frame->len;
      memcpy(copy, frame->buf, length);
      esp_camera_fb_return(frame);
    }
    // Network sends use a private copy, never holding camera/servo mutex.
    char header[100];
    const int headerLength = snprintf(header, sizeof(header),
      "\r\n--frame\r\nContent-Type: image/jpeg\r\nContent-Length: %u\r\n\r\n", static_cast<unsigned>(length));
    const uint32_t sendStarted = millis();
    result = httpd_resp_send_chunk(req, header, headerLength);
    if (result == ESP_OK) result = httpd_resp_send_chunk(req, reinterpret_cast<const char *>(copy), length);
    maxSendWaitMs = max(maxSendWaitMs, millis() - sendStarted);
    if (result != ESP_OK) break;
    ++streamFrames;
    if (millis() - lastStreamLog >= 10000) {
      Serial.printf("stream socket=%d frames=%lu RSSI=%d max_frame_wait_ms=%lu max_send_wait_ms=%lu\n",
                    socket, static_cast<unsigned long>(streamFrames), WiFi.RSSI(),
                    static_cast<unsigned long>(maxFrameWaitMs), static_cast<unsigned long>(maxSendWaitMs));
      maxFrameWaitMs = maxSendWaitMs = 0;
      lastStreamLog = millis();
    }
    const uint32_t elapsed = millis() - frameCycleStarted;
    delay(elapsed < STREAM_INTERVAL_MS ? STREAM_INTERVAL_MS - elapsed : 1);
  }
  free(copy);
  Serial.printf("stream close socket=%d frames=%lu result=0x%x max_frame_wait_ms=%lu max_send_wait_ms=%lu\n",
                socket, static_cast<unsigned long>(streamFrames), result,
                static_cast<unsigned long>(maxFrameWaitMs), static_cast<unsigned long>(maxSendWaitMs));
  // Force HTTPD to close this streaming session rather than retaining it as an
  // idle keep-alive connection after a half-close.
  return result == ESP_OK ? ESP_FAIL : result;
}
bool addRoute(httpd_handle_t server, const char *path, esp_err_t (*handler)(httpd_req_t *)) {
  httpd_uri_t route = {};
  route.uri = path; route.method = HTTP_GET; route.handler = handler;
  return httpd_register_uri_handler(server, &route) == ESP_OK;
}
esp_err_t configureHttpSocket(httpd_handle_t, int socket) {
  const int enabled = 1;
  if (setsockopt(socket, IPPROTO_TCP, TCP_NODELAY, &enabled, sizeof(enabled)) != 0) {
    Serial.printf("ERROR TCP_NODELAY socket=%d errno=%d\n", socket, errno);
    return ESP_FAIL;
  }
  return ESP_OK;
}
void startServers() {
  httpd_config_t config = HTTPD_DEFAULT_CONFIG();
  // Control replies and multipart headers should not wait for TCP coalescing.
  config.open_fn = configureHttpSocket;
  config.server_port = 80; config.stack_size = 12288;
  config.lru_purge_enable = true; config.recv_wait_timeout = 3; config.send_wait_timeout = 15;
  if (httpd_start(&controlServer, &config) != ESP_OK ||
      !addRoute(controlServer, "/move", moveHandler) || !addRoute(controlServer, "/status", statusHandler) ||
      !addRoute(controlServer, "/capture", captureHandler) || !addRoute(controlServer, "/ack", ackHandler))
    fatal("control HTTP server failed");
  config.server_port = 81; config.ctrl_port += 1; config.stack_size = 8192;
  config.send_wait_timeout = 5;
  if (httpd_start(&streamServer, &config) != ESP_OK || !addRoute(streamServer, "/stream", streamHandler))
    fatal("stream HTTP server failed");
  Serial.printf("HTTP ready: http://%s/status stream=http://%s:81/stream\n",
    WiFi.localIP().toString().c_str(), WiFi.localIP().toString().c_str());
}
void servoTask(void *) {
  while (true) {
    {
      ServoLock lock(1);
      if (lock.acquired && !capturePending) {
        const int panStep = constrain(targetPan - actualPan, -SLEW_DEG, SLEW_DEG);
        const int tiltStep = constrain(targetTilt - actualTilt, -SLEW_DEG, SLEW_DEG);
        if (panStep) { actualPan += panStep; panServo.write(actualPan); }
        if (tiltStep) { actualTilt += tiltStep; tiltServo.write(actualTilt); }
        if (moveInProgress && actualPan == targetPan && actualTilt == targetTilt) {
          moveSettledMs = millis();
          moveInProgress = false;
        }
      }
    }
    // Never catch up missed periods with a burst of servo writes.
    vTaskDelay(pdMS_TO_TICKS(SERVO_INTERVAL_MS));
  }
}
void setup() {
  Serial.begin(115200); delay(1500);
  Serial.printf("camera_head boot reset_reason=%d\n", static_cast<int>(esp_reset_reason()));
  if (!psramFound()) fatal("PSRAM missing; enable OPI PSRAM for N16R8");
  Serial.printf("PSRAM bytes=%u free=%u\n", static_cast<unsigned>(ESP.getPsramSize()), static_cast<unsigned>(ESP.getFreePsram()));
  cameraMutex = xSemaphoreCreateMutex();
  servoMutex = xSemaphoreCreateMutex();
  if (!cameraMutex || !servoMutex) fatal("mutex allocation failed");
  camera_config_t config = {};
  config.ledc_channel = LEDC_CHANNEL_7; config.ledc_timer = LEDC_TIMER_3;
  config.pin_d0 = Y2_GPIO_NUM; config.pin_d1 = Y3_GPIO_NUM;
  config.pin_d2 = Y4_GPIO_NUM; config.pin_d3 = Y5_GPIO_NUM;
  config.pin_d4 = Y6_GPIO_NUM; config.pin_d5 = Y7_GPIO_NUM;
  config.pin_d6 = Y8_GPIO_NUM; config.pin_d7 = Y9_GPIO_NUM;
  config.pin_xclk = XCLK_GPIO_NUM; config.pin_pclk = PCLK_GPIO_NUM;
  config.pin_vsync = VSYNC_GPIO_NUM; config.pin_href = HREF_GPIO_NUM;
  config.pin_sccb_sda = SIOD_GPIO_NUM; config.pin_sccb_scl = SIOC_GPIO_NUM;
  config.pin_pwdn = PWDN_GPIO_NUM; config.pin_reset = RESET_GPIO_NUM;
  config.xclk_freq_hz = 20000000; config.pixel_format = PIXFORMAT_JPEG;
  config.frame_size = FRAMESIZE_QXGA; config.jpeg_quality = 12;
  config.fb_count = 2; config.fb_location = CAMERA_FB_IN_PSRAM; config.grab_mode = CAMERA_GRAB_LATEST;
  const esp_err_t result = esp_camera_init(&config);
  if (result != ESP_OK) {
    Serial.printf("ERROR camera init=0x%x; check ribbon and documented pins\n", result);
    fatal("camera initialization failed");
  }
  sensor_t *sensor = esp_camera_sensor_get();
  Serial.printf("Camera sensor PID=0x%x\n", sensor->id.PID);
  if (sensor->id.PID != OV3660_PID) fatal("sensor differs from user-confirmed OV3660");
  if (sensor->set_framesize(sensor, FRAMESIZE_QVGA) != 0) fatal("QVGA configuration failed");
  panServo.setPeriodHertz(50); tiltServo.setPeriodHertz(50);
  panServo.attach(1, 500, 2400); tiltServo.attach(2, 500, 2400);
  if (!panServo.attached() || !tiltServo.attached()) fatal("servo attachment failed");
  // F1 horns were aligned at 90/90. No measured physical position is available.
  panServo.write(90); tiltServo.write(90);
  if (xTaskCreate(servoTask, "servo_slew", 3072, nullptr, 2, nullptr) != pdPASS)
    fatal("servo task allocation failed");
  Serial.println("Servo centre90/90; slew2deg/20ms; no automatic sweep.");
  if (!strcmp(WIFI_SSID, "REPLACE_LOCALLY") || !strcmp(WIFI_PASS, "REPLACE_LOCALLY"))
    fatal("configure ignored secrets.h Wi-Fi credentials");
  WiFi.persistent(false); WiFi.mode(WIFI_STA); WiFi.setSleep(false); WiFi.setAutoReconnect(true);
  WiFi.onEvent([](WiFiEvent_t, WiFiEventInfo_t info) {
    wifiDisconnectReason = info.wifi_sta_disconnected.reason;
    ++wifiDisconnects;
  }, ARDUINO_EVENT_WIFI_STA_DISCONNECTED);
#if !WIFI_USE_DHCP
  if (S3_IP == IPAddress(0, 0, 0, 0) || !WiFi.config(S3_IP, GATEWAY, SUBNET)) fatal("confirmed static IPv4 settings required");
#endif
  WiFi.begin(WIFI_SSID, WIFI_PASS);
  Serial.printf("Wi-Fi starting; addressing=%s\n", WIFI_USE_DHCP ? "DHCP bench" : "static");
}
void loop() {
  static uint32_t lastDisconnectReport = 0, reportedDisconnects = 0;
  if (millis() - lastDisconnectReport >= 2000 && wifiDisconnects != reportedDisconnects) {
    reportedDisconnects = wifiDisconnects;
    lastDisconnectReport = millis();
    Serial.printf("Wi-Fi disconnected reason=%u count=%lu\n", wifiDisconnectReason,
                  static_cast<unsigned long>(reportedDisconnects));
  }
  static uint32_t lastRetry = 0;
  static int lastWifi = -1;
  const uint32_t now = millis();
  const int wifi = WiFi.status();
  if (wifi != lastWifi) {
    Serial.printf("Wi-Fi state=%d\n", wifi); lastWifi = wifi;
    if (wifi == WL_CONNECTED) Serial.printf("Wi-Fi connected IP=%s RSSI=%d\n", WiFi.localIP().toString().c_str(), WiFi.RSSI());
  }
  if (wifi == WL_CONNECTED && !controlServer) startServers();
  if (wifi != WL_CONNECTED && now - lastRetry >= 10000) {
    lastRetry = now; Serial.println("Wi-Fi reconnect attempt"); WiFi.reconnect();
  }
  delay(2);
}

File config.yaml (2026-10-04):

# DHCP board addresses verified on new hotspot, 2026-10-04. Phase5 mocks are separate.
s3_ip: 172.20.10.5
c3_ip: 172.20.10.4
unoq_ip: 172.20.10.2
camera_http_port: 80
camera_stream_port: 81
audio_port: 5005
light_port: 5006
shoot_port: 5007
gallery_port: 8080
detect_every_n_frames: 5
dead_zone: 0.08
gain_deg: 12
max_step_deg: 4
pan_min: 10
pan_max: 170
tilt_min: 40
tilt_max: 140
invert_pan: false
invert_tilt: false
vosk_conf_threshold: 0.7
centre_timeout_s: 1.5
# Relative paths resolve from the configuration file's directory.
photos_dir: photos

# Optional eSpeak replies; no-op when disabled or unavailable.
speaker_enabled: false

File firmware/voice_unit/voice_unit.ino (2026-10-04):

#include <Arduino.h>
#include <WiFi.h>
#include <WiFiUdp.h>
#include <ESP_I2S.h>
#include <Adafruit_NeoPixel.h>
#include <esp_system.h>
#include <esp_wifi.h>
#include <freertos/queue.h>
#include <stdarg.h>
#include <errno.h>
#if __has_include("secrets.h")
#include "secrets.h"
#else
#include "../secrets.example.h"
#endif
#ifndef WIFI_USE_DHCP
#define WIFI_USE_DHCP 0
#endif
#ifndef SHIFT
#define SHIFT 14
#endif
static_assert(SHIFT >= 0 && SHIFT <= 31, "SHIFT must be 0..31");
// Optional IR is deliberately omitted from this prototype.
constexpr size_t SAMPLE_COUNT = 512;
constexpr uint16_t AUDIO_PORT = 5005, LIGHT_PORT = 5006;
enum class Light { Ready, Heard, Tracking, NoSubject, Saved, Error, Reconnect, Sleep };
struct LogLine { char text[192]; };
QueueHandle_t logQueue = nullptr;

// Producers never call USB Serial or wait for a host to consume debug output.
void logMessage(const char *format, ...) {
  if (!logQueue) return;
  LogLine line;
  va_list args;
  va_start(args, format);
  vsnprintf(line.text, sizeof(line.text), format, args);
  va_end(args);
  xQueueSend(logQueue, &line, 0); // Drop logs when full; never backpressure audio.
}

void pollLogs() {
  if (!Serial) return;
  LogLine line;
  for (unsigned i = 0; i < 4 && xQueuePeek(logQueue, &line, 0) == pdTRUE; ++i) {
    const size_t length = strlen(line.text);
    if (Serial.availableForWrite() < static_cast<int>(length)) return;
    xQueueReceive(logQueue, &line, 0);
    Serial.write(reinterpret_cast<const uint8_t *>(line.text), length);
  }
}
I2SClass microphone;
Adafruit_NeoPixel pixel(1, 7, NEO_GRB + NEO_KHZ800);
WiFiUDP lightSocket;
Light steady = Light::Ready, transient = Light::Ready;
bool transientActive = false;
uint32_t transientStarted = 0, steadyStarted = 0, rendered = UINT32_MAX;

void show(uint32_t colour) {
  if (colour != rendered) { rendered = colour; pixel.setPixelColor(0, colour); pixel.show(); }
}
void fatal(const char *message) {
  logMessage("FATAL %s; correct configuration and reset\n", message);
  show(pixel.Color(255, 0, 0));
  while (true) { if (logQueue) pollLogs(); delay(1000); }
}
bool parseLight(const char *name, Light &result) {
  const char *names[] = {"ready", "heard", "tracking", "nosubject", "saved", "error", "reconnect", "sleep"};
  const Light values[] = {Light::Ready, Light::Heard, Light::Tracking, Light::NoSubject,
                         Light::Saved, Light::Error, Light::Reconnect, Light::Sleep};
  for (size_t i = 0; i < 8; ++i) {
    if (!strcmp(name, names[i])) { result = values[i]; return true; }
  }
  return false;
}
void acceptLight(Light state) {
  if (state == Light::Heard || state == Light::Saved || state == Light::Error) {
    transient = state; transientActive = true; transientStarted = millis();
  } else { steady = state; steadyStarted = millis(); transientActive = false; }
}
void updateLight(bool connected) {
  const uint32_t now = millis();
  if (!connected) { show((now / 500) % 2 ? 0 : pixel.Color(150, 0, 255)); return; }
  if (transientActive) {
    const uint32_t age = now - transientStarted;
    const uint32_t duration = transient == Light::Error ? 600 : 300;
    if (age < duration) {
      if (transient == Light::Error) show((age / 150) % 2 ? 0 : pixel.Color(255, 0, 0));
      else show(transient == Light::Heard ? pixel.Color(0, 0, 255) : pixel.Color(255, 255, 255));
      return;
    }
    transientActive = false;
  }
  const bool blink = ((now - steadyStarted) / 500) % 2 == 0;
  switch (steady) {
    case Light::Ready: show(pixel.Color(0, 180, 0)); break;
    case Light::Tracking: show(pixel.Color(0, 255, 255)); break;
    case Light::NoSubject: show(blink ? pixel.Color(255, 100, 0) : 0); break;
    case Light::Reconnect: show(blink ? pixel.Color(150, 0, 255) : 0); break;
    default: show(0); break;
  }
}
void audioTask(void *) {
  // This socket and its reconnect operations belong exclusively to this task.
  WiFiUDP audioSocket;
  int32_t raw[SAMPLE_COUNT];
  uint8_t pcm[SAMPLE_COUNT * 2];
  size_t collected = 0;
  bool socketReady = false;
  uint32_t sent = 0, failed = 0, lastReport = millis(), lastError = 0;
  uint32_t sendRetries = 0;
  int lastSendErrno = 0;
  const char *lastSendStage = "none";
  while (true) {
    const size_t bytes = microphone.readBytes(reinterpret_cast<char *>(raw + collected),
                                             (SAMPLE_COUNT - collected) * sizeof(int32_t));
    if (!bytes || bytes % sizeof(int32_t)) {
      collected = 0;
      if (millis() - lastError >= 2000) {
        logMessage("ERROR I2S bytes=%u code=%d\n", static_cast<unsigned>(bytes), microphone.lastError());
        lastError = millis();
      }
      vTaskDelay(pdMS_TO_TICKS(10)); continue;
    }
    collected += bytes / sizeof(int32_t);
    if (collected < SAMPLE_COUNT) continue;
    collected = 0;
    if (WiFi.status() != WL_CONNECTED) {
      if (socketReady) audioSocket.stop();
      socketReady = false; continue; // Drain mic offline; never replay old audio.
    }
    if (!socketReady) {
      errno = 0;
      socketReady = audioSocket.begin(0) != 0;
      if (!socketReady) { lastSendErrno = errno; lastSendStage = "socket"; }
    }
    for (size_t i = 0; i < SAMPLE_COUNT; ++i) {
      const int32_t value = constrain(raw[i] >> SHIFT, -32768, 32767);
      const uint16_t bits = static_cast<uint16_t>(static_cast<int16_t>(value));
      pcm[2 * i] = bits & 0xff; pcm[2 * i + 1] = bits >> 8;
    }
    bool ok = socketReady;
    if (ok) {
      errno = 0;
      ok = audioSocket.beginPacket(UNOQ_IP, AUDIO_PORT) != 0;
      if (!ok) { lastSendErrno = errno; lastSendStage = "begin"; }
    }
    if (ok) {
      errno = 0;
      const size_t written = audioSocket.write(pcm, sizeof(pcm));
      if (written != sizeof(pcm)) { lastSendErrno = errno; lastSendStage = "write"; }
      errno = 0;
      bool delivered = audioSocket.endPacket() != 0;
      int sendError = delivered ? 0 : errno;
      const uint32_t retryStarted = millis();
      // ENOMEM/EAGAIN are network backpressure, not a broken UDP socket.
      // Retry only a failed send, within16ms; never duplicate a successful send
      // or retain audio through a disconnection. endPacket preserves its buffer.
      while (!delivered && written == sizeof(pcm) &&
             (sendError == ENOMEM || sendError == EAGAIN) &&
             WiFi.status() == WL_CONNECTED && millis() - retryStarted < 16) {
        vTaskDelay(max(static_cast<TickType_t>(1), pdMS_TO_TICKS(2)));
        if (millis() - retryStarted >= 16 || WiFi.status() != WL_CONNECTED) break;
        ++sendRetries;
        errno = 0;
        delivered = audioSocket.endPacket() != 0;
        sendError = delivered ? 0 : errno;
      }
      if (!delivered) { lastSendErrno = sendError; lastSendStage = "send"; }
      ok = written == sizeof(pcm) && delivered;
    }
    if (ok) ++sent;
    else {
      ++failed;
      if (strcmp(lastSendStage, "send") != 0 ||
          (lastSendErrno != ENOMEM && lastSendErrno != EAGAIN)) {
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

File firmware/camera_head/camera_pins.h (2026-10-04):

#pragma once
// Camera signals transcribed from the user's ESP32-S3-CAM N16R8 diagram.
// Matches Arduino-ESP32 3.3.11 CameraWebServer ESP32S3_EYE camera wiring.
// The two -1 values come from that matching core definition; the supplied
// diagram does not expose PWDN/RESET. Bench boot confirmed OV3660 PID0x3660.
#define PWDN_GPIO_NUM -1
#define RESET_GPIO_NUM -1
#define XCLK_GPIO_NUM 15
#define SIOD_GPIO_NUM 4
#define SIOC_GPIO_NUM 5
#define Y2_GPIO_NUM 11
#define Y3_GPIO_NUM 9
#define Y4_GPIO_NUM 8
#define Y5_GPIO_NUM 10
#define Y6_GPIO_NUM 12
#define Y7_GPIO_NUM 18
#define Y8_GPIO_NUM 17
#define Y9_GPIO_NUM 16
#define VSYNC_GPIO_NUM 6
#define HREF_GPIO_NUM 7
#define PCLK_GPIO_NUM 13

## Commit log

2026-10-03 fw docs: record board wiring and camera pinout for team review
2026-10-04 fw phase 2: implement S3 camera head and servo control
2026-10-04 feat: publish live tracking, C3 firmware and enclosure models
    [C1.stl, C1_vertical.stl, C2.stl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]
2026-10-04 fix: prevent C3 logging stalls and add runtime recovery
    [voice_unit.ino]
2026-10-04 feat: add switchable BLE voice transport and network diagnostics

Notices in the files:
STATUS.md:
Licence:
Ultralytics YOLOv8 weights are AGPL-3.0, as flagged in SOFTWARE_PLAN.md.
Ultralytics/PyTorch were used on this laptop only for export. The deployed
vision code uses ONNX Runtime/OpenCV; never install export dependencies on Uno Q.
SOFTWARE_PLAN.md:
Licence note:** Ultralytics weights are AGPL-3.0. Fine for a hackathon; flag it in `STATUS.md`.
